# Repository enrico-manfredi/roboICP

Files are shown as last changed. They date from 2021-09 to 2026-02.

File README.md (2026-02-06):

# roboICP

**roboICP** is an open-source laboratory automation platform for **high-throughput preparation of dissolution samples for ICP-AES / ICP-OES analysis**.  
The system automates repetitive and error-prone steps—solid dosing, reaction handling, vial filling, and dilution—using a modular combination of mechanical hardware, embedded control, and Python-based orchestration.

The project was developed to support materials and chemical research workflows where **large sample volumes**, **tight mass/volume control**, and **reproducibility** are required, and where manual preparation becomes a throughput bottleneck.

---

## Project goals

- Automate dissolution-to-vial workflows for ICP analysis  
- Improve **repeatability, throughput, and operator time efficiency**
- Enable **scalable sample counts** without proportional increases in labour
- Provide a **transparent, hackable platform** suitable for research labs

---

## System overview

roboICP integrates mechanical hardware, embedded control, and high-level software into a single automated workflow.

Key elements include:
- Reaction vessels and mixing hardware
- Automated vial handling and filling
- Automated solid dispensing
- Arduino-based low-level control of motors, actuators, and timing-critical tasks
- Python scripts and Jupyter notebooks for protocol definition, execution logic, and data logging

The system is intentionally modular: individual subsystems can be modified or replaced without redesigning the entire platform.

---

## Key design iterations (Mk1 → Mk2)

This repository documents multiple design iterations developed through hands-on operation.

**Mk2 hardware changes were driven by real operational bottlenecks identified during Mk1 use**, rather than theoretical design optimisation.

### New vial holder
- Increased total vial capacity
- Improved mechanical alignment and repeatability
- Enabled **simultaneous vial handling**, reducing cycle time per batch

### New solid feeder
- Developed to address **reliable automated solid dispensing**, a well-known challenge in laboratory automation
- Supports controlled dosing of solids and improved consistency across samples
- Designed to integrate directly with automated reaction and dilution workflows

Automated solids handling is substantially more difficult than liquid dispensing due to flow variability, bridging, and adhesion.  
The Mk2 solid feeder was developed specifically to address these issues rather than avoid them.

Design rationale, assembly details, and lessons learned are documented in the accompanying documentation and presentation files.

---

## Documentation

The repository includes detailed written documents and slide decks covering:
- Physical assembly of the system
- Mechanical and control design decisions
- Limitations observed during Mk1 operation
- Proposed architecture and improvements for Mk2

These materials are intended to make the system understandable and reproducible beyond the source code alone.

---

## Intended users

- Research labs running **ICP-AES / ICP-OES** with high sample volumes
- Chemists and materials scientists interested in **laboratory automation**
- Engineers working on **mechatronics for chemical workflows**
- Employers assessing practical experience in:
  - hardware–software integration
  - experimental automation
  - iterative prototyping under real constraints

---

## Current status and limitations

- The system is a **research-grade automation platform**, not a commercial product
- Safety, calibration, and compliance must be validated for each laboratory environment
- Hardware designs are provided as-is and may require adaptation

---

## Authors and contributors

**Primary author and system architect**  
**Enrico Manfredi**  
Overall system design, mechanical architecture, experimental specification, hardware–software integration, iterative Mk1 → Mk2 development, and project direction.

**Contributors**

**Sarthak Das** — Paid summer intern  
Worked on development of the **initial control code and concepts** for the solids hopper, rail-based filtration system, and elements of the dilution workflow.  
Also contributed CAD and documentation files included in this repository.

**Dewen Sun** — Paid summer intern  
Worked on development of the **initial automation logic and control scripts** for solids handling concepts, filtration workflow, and dilution system sequencing.  
Contributions focused on early-stage prototyping and proof-of-concept implementations.

*Note: Contributors were engaged as paid summer interns and worked on specific subsystems under supervision.  
System integration, final architecture, validation, and subsequent design iterations were led and completed by the primary author.*

---

## License

This project is released under the **MIT License**.  
You are free to use, modify, and build upon it with attribution.

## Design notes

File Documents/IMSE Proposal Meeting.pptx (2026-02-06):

## Old Machine

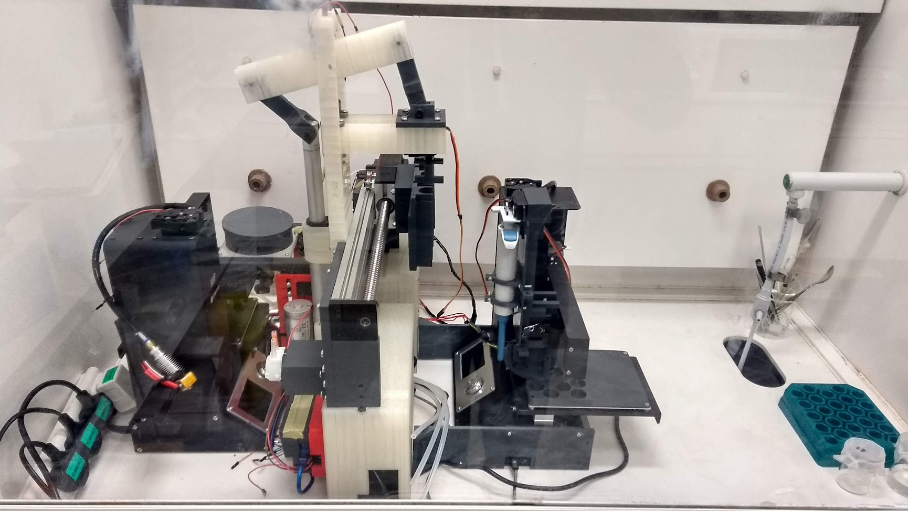
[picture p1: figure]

Filtering System

Dilution system

Reaction System

## New Machine

Dilution system

- Creality CR10-S Max Printer
  - £550
  - Large buildplate
  - Dual screw z-axis for fast and high force z movement
- Additional consumables
  - Pipette tips
  - Syringes
  - Check valves
  - Tubing
  - Syringe filters
  - Vials
  - Mixing impellers (printable)
  - Peristaltic Pumps
  - Additional microcontroller (for external and head mounted systems)
- Most budget can be spent at the start of the project through ordering necessary parts
  - Some contingency budget needed to buy additional consumables as needs arise

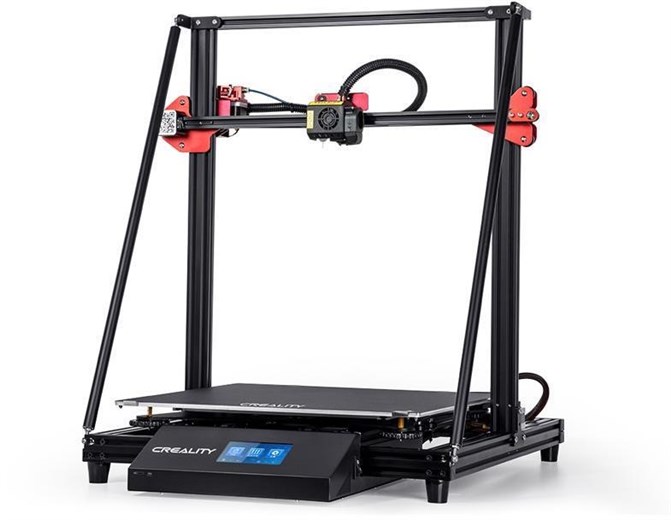
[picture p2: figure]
Creality CR-10 Max 3D Printer, CR10M

Whole system in a single footprint greatly simplifies operation & maintenance

Filtering System

Dilution system

Reaction System

## Plate Layout

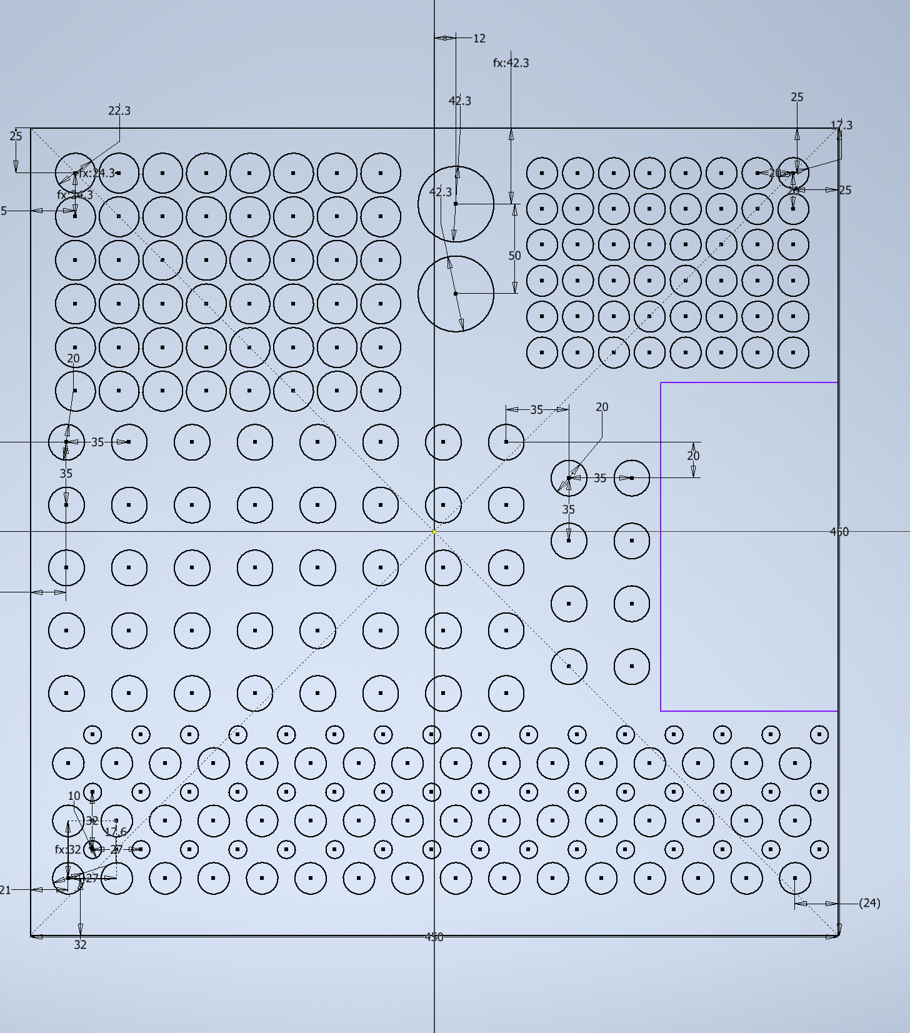
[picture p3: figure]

Priming Bins
(acid & DES)

Mixing Vials

ICP Tubes

48 Samples on plate in this configuration

Pipette tips

Waste Area

Syringe
Collection Spouts

Syringes

## Features

- Long reactions with precise time information and event logging possible without supervision
- Whole setup fits in a standard fume hood – scalable with no additional lab modifications required even when handling toxic samples
- Self-building: since all of the components will be fitted within the machine print area – all parts of the machine can be printed by the printer before it is then modified for chemistry
- Low cost & open source – development cost will be around £10K but finalised build cost should be significantly lower – all code can be published on an open repository and all parts used are widely available, so it can be modified and iterated by other uses as needed
- Can handle and filter liquids with high viscosity and solid loadings (e.g. 10,000 cP, 25 v% particulate loadings)

## Build Timeline

- All funds can be spent by the project deadline (30th June) with a full design delivered
- Machine probably won’t be operational until Jan ‘23 due to other work I need to complete for my PhD (experimental cycles using old machine) and inevitable problems in the building process
- 3 month verification period for new machine between Feb and April ’23
- I will need external help from experienced engineers for CAD and build (since consumables take half the limit, the other half could be used to hire one?)

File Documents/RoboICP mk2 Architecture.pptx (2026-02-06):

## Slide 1

Synthesis

Reaction

Solids Dispenser

Container

Mixer

Filtering

Power Unit

Filter Element

Container

Dilution

Acid Dispenser

Filtrate Dispenser

Sample Container

1

2

Solids Dispenser

Heater

Liquid Dispenser

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
Container

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
Mixer

Control Computer

13

18

7

8

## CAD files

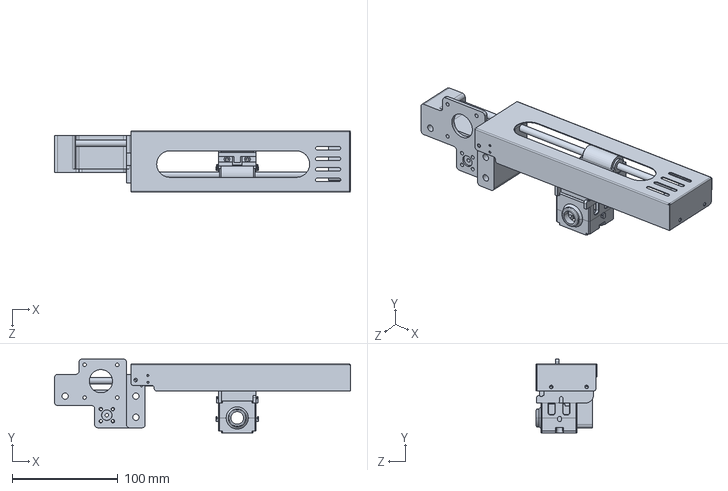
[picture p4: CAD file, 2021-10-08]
Reaction System/Full Assembly/X-axis full model.SLDPRT
280.5 x 70.1 x 58.3 mm

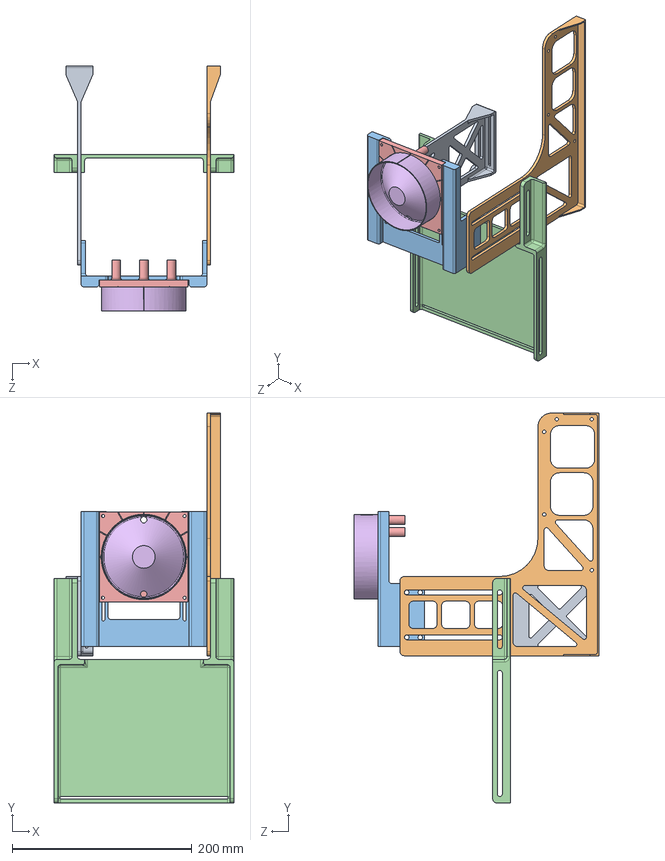
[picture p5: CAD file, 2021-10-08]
Reaction System/Full Assembly/Feeder assembly.SLDASM
200.0 x 434.2 x 273.2 mm
Feeder rail support_Left
Feeder rail support_Right
feeder rail 2.0
Arduino Support
Outer Cap 4.0
Inner cap 3.0_with marking

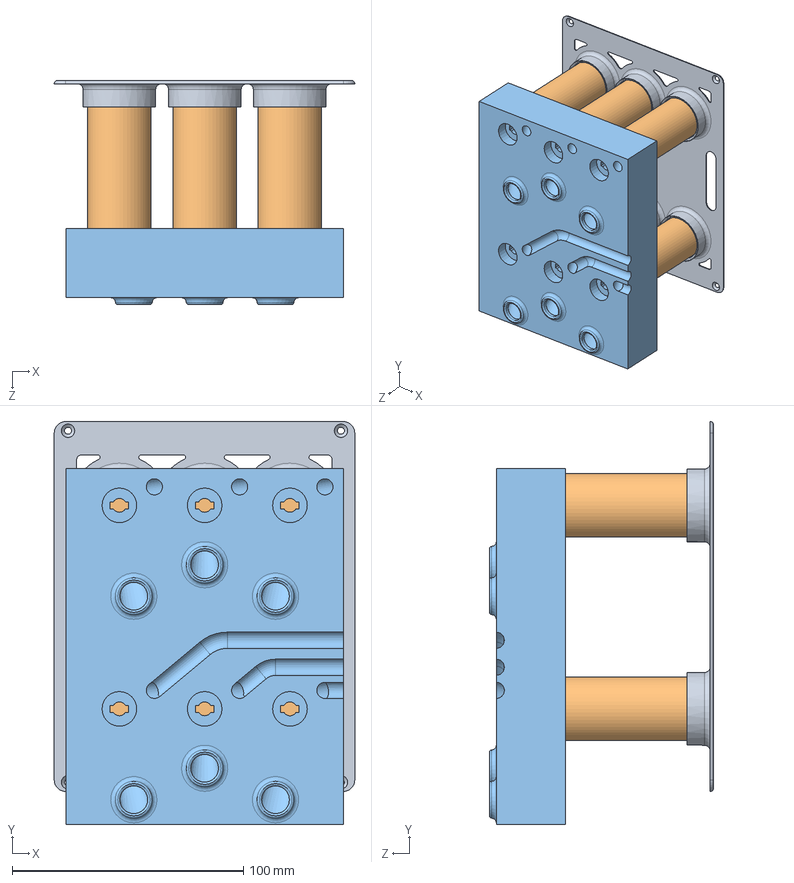
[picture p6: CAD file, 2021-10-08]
Reaction System/Full Assembly/Vial assembly.SLDASM
130.0 x 174.3 x 97.0 mm
Bottom 2.0
vial x 6
New Top 4.0_Mirrored

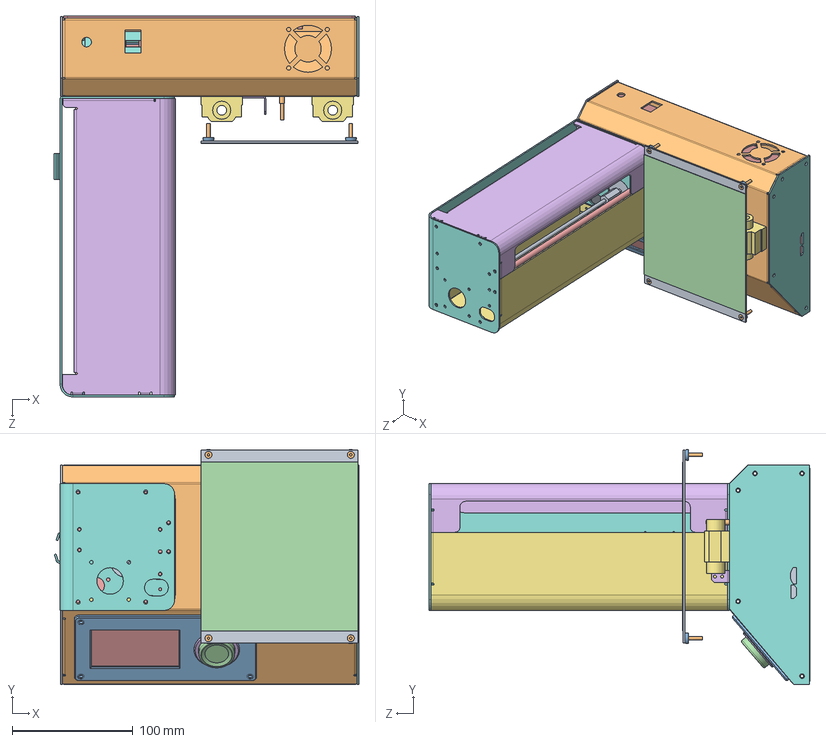
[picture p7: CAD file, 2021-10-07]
Reaction System/Full assembly_reaction system/Select mini V2_modified.SLDASM
252.4 x 194.9 x 315.8 mm
Heatbed_1.step
Bed Level Screw_4.step x 4
Bed Spring Cap_8.step x 4
Print Surface_1.step
Bottom Cover_1.step
Y Axix Endstop Mount_1.step
X Bearing Blocks.step x 2
Right Cover.step
Left Cover.step
Frame.step
Control Panel Cover_1.step
Knob_1.step
LCD and UI Ctrl_1.step
Knob Light Pipe_1.step
Encoder_1.step
Control Panel Back Frame_1.step
Z Rod Holder Single.step x 2
Z Rod Holder Double.step x 2
Z Rod Spacer Single.step x 4
Z Rod Spacer Double.step x 4
Z Linear Rod.step x 3
Tower Back Cover.step
Tower Front Cover.step
Tower Frame_1.step
Z Stepper and Screw_1.step

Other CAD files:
Reaction System/Full assembly_reaction system/Control Panel_1.step.SLDASM
Reaction System/Full assembly_reaction system/Control Panel Back Frame.step.SLDASM
Reaction System/Full assembly_reaction system/Bed Spring Cap_5.step.SLDASM
Reaction System/Full assembly_reaction system/Y Axis Bearing Block_1.step.SLDASM
Reaction System/Full assembly_reaction system/Y Axix Endstop Mount.step.SLDASM
Reaction System/Full assembly_reaction system/Heatbed.step.SLDASM
Reaction System/Full assembly_reaction system/Base_1.step.SLDASM
Reaction System/Full assembly_reaction system/Bed Spring Cap_6.step.SLDASM
Reaction System/Full assembly_reaction system/Z Rod Holders.step.SLDASM
Reaction System/Full assembly_reaction system/Control Panel Cover.step.SLDASM
Reaction System/Full assembly_reaction system/LCD and UI Ctrl.step.SLDASM
Reaction System/Full assembly_reaction system/Bed Spring Cap.step.SLDASM
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

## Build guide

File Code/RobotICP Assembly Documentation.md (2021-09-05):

# RobotICP Assembly Documentation

# Software Testing

- On assembly run each file ending with [Lib.py](http://lib.py) to ensure that component is operating correctly
- Calibrate Variables depending on physical location of each component

    ### LinearRailLib.py

    ```python
    self.steps_per_syringe = 50000
    self.first_pos = 3600 * 5
    ```

    First change steps per syringe for the distance in number of steps between each syringe

    Secod first_pos is the number of steps to align the first syringe with the actuator

    ### ServoLib.py

    Change the duty cycle depending on starting angle and finishing angle of all press and relsease, depends on the mounting position

    ### PrinterLib.py

    ```python
    self.vialPickupPos = [70,103,6]
    self.tipPickupPos = [51,103,6]
    self.vialDropoffPos = [[25,50,40], 
                            [45,50,40], 
                            [75,50,40], 
                            [95,50,40], 
                            [95,74,40]]
    self.vialAcidDropoffPos = [[0,31,0], 
                            [25,31,0], 
                            [51,31,0], 
                            [73,31,0], 
                            [73,61,0]]

    self.dumpPos = [0,70,48]
    ```

    Change all of these coordinates depending on where they are located on the printer bed, Use Repetier to quickly find the coordinates of the components

    ### [PumpLib.py](http://pumplib.py)

    ```python
    self.dispense(40)
    ```

    Change the number in this for the amount of dead volume in the system to fill the pipes with adic

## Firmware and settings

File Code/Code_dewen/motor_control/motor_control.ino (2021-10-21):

#include <Adafruit_MotorShield.h>

Adafruit_MotorShield AFMS = Adafruit_MotorShield();

Adafruit_DCMotor *myDC = AFMS.getMotor(1);

Adafruit_StepperMotor *myStepper = AFMS.getStepper(200,2);
void setup() {
  Serial.begin(9600);           // set up Serial library at 9600 bps

  if (!AFMS.begin()) {
    Serial.println("Could not find Motor Shield. Check wiring.");
    while (1);
  }
  Serial.println("Motor Shield found.");

  // Set the speed to start, from 0 (off) to 255 (max speed)
  myDC->setSpeed(255);
  myStepper -> setSpeed(1);
}

void loop() {
 if(Serial.available()>0) {
  char index = Serial.read();
  if ((index >= '0') && (index <= '5')){
    Serial.println("Rotating Feeder");
    myStepper -> step(100, BACKWARD, DOUBLE);
    delay(5000);
     
    Serial.println("stiring");
    myDC -> run(FORWARD);
    delay(10000);
    myDC -> run(RELEASE);
  }
 }
}

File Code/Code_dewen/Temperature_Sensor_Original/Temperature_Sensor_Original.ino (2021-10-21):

#include <OneWire.h>
#include <DallasTemperature.h>

// Data wire is plugged into digital pin 2 on the Arduino
#define ONE_WIRE_BUS 2

// Setup a oneWire instance to communicate with any OneWire device
OneWire oneWire(ONE_WIRE_BUS);  

// Pass oneWire reference to DallasTemperature library
DallasTemperature sensors(&oneWire);

int deviceCount = 0;
float tempC;

void setup(void)
{
  sensors.begin();  // Start up the library
  Serial.begin(9600);
  
  // locate devices on the bus
  Serial.print("Locating devices...");
  Serial.print("Found ");
  deviceCount = sensors.getDeviceCount();
  Serial.print(deviceCount, DEC);
  Serial.println(" devices.");
  Serial.println("");
}

void loop(void)
{ 
  // Send command to all the sensors for temperature conversion
  sensors.requestTemperatures(); 
  
  // Display temperature from each sensor
  for (int i = 0;  i < deviceCount;  i++)
  {
    Serial.print("Sensor ");
    Serial.print(i+1);
    Serial.print(" : ");
    tempC = sensors.getTempCByIndex(i);
    Serial.print(tempC);
    Serial.print((char)176);//shows degrees character
    Serial.print("C  |  ");
    Serial.print(DallasTemperature::toFahrenheit(tempC));
    Serial.print((char)176);//shows degrees character
    Serial.println("F");
  }
  
  Serial.println("");
  delay(1000);
}

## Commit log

2021-09-28 Update actuatorLib.py
    -added comments and docstrings to functions
    -capitalised class name to "Actuator"
    -re-write of testing script to reset before push in case of previous outrun, renamed methods to match updated class methods
    [actuatorLib.py]
2021-09-28 Update actuatorTest.py
    -added query pointing to import
    -captialised class to match changes to imported script
2021-10-04 Delete Reaction System directory
    Old versions of the design are not needed anymore
    [Bottom.SLDPRT, Channel.SLDPRT, Full system assembly.SLDASM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]
2021-10-04 Add files via upload
    All the parts files from Dewen
    [Arduino Support.SLDPRT, Arduino Support.STL, Bottom 2.0.SLDPRT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]
2021-10-07 STL and STEP Files
    [Body Pippete Holder v2.stl, Body Pippete Holder v3.step, Micropippete mount v11.stl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]
2021-11-10 Add files via upload
    The original and shortened mixer
    [Mixer 2.0 (shortened).SLDPRT, Mixer.SLDPRT]
2026-02-06 Final Assembly Inventor & STL Files Pt. 1
    [Dilution Printer.0005.iam, Linear Bearing_MIR2.0001.ipt, Linear Bearing_MIR2_MIR.0001.ipt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]
2026-02-06 Create Final Assembly Folder
2026-02-06 Revert "Create Final Assembly Folder"
    This reverts commit 388193a3b02d5a75bcd57e927d29c365bc15f482.
2026-02-06 Revert "Final Assembly Inventor & STL Files Pt. 1"
    This reverts commit cbca9e76a4878e03697cbc09f6b3d9a88b343620.
    [Dilution Printer.0005.iam, Linear Bearing_MIR2.0001.ipt, Linear Bearing_MIR2_MIR.0001.ipt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]
2026-02-06 Added additional files from Onedrive
    [6x250 steel rod.ipt, Actuator key v2.ipt, ArduinoMega_STEP_AP203.ipt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]
